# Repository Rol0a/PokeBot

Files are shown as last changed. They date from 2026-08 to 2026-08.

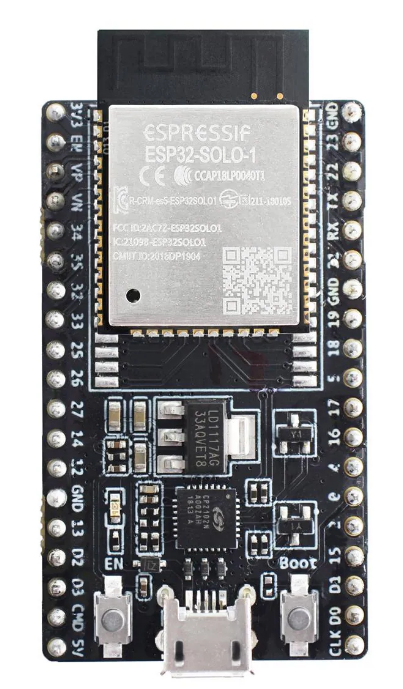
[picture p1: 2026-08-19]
FabricationOutputs/ESP32_FRONT.png

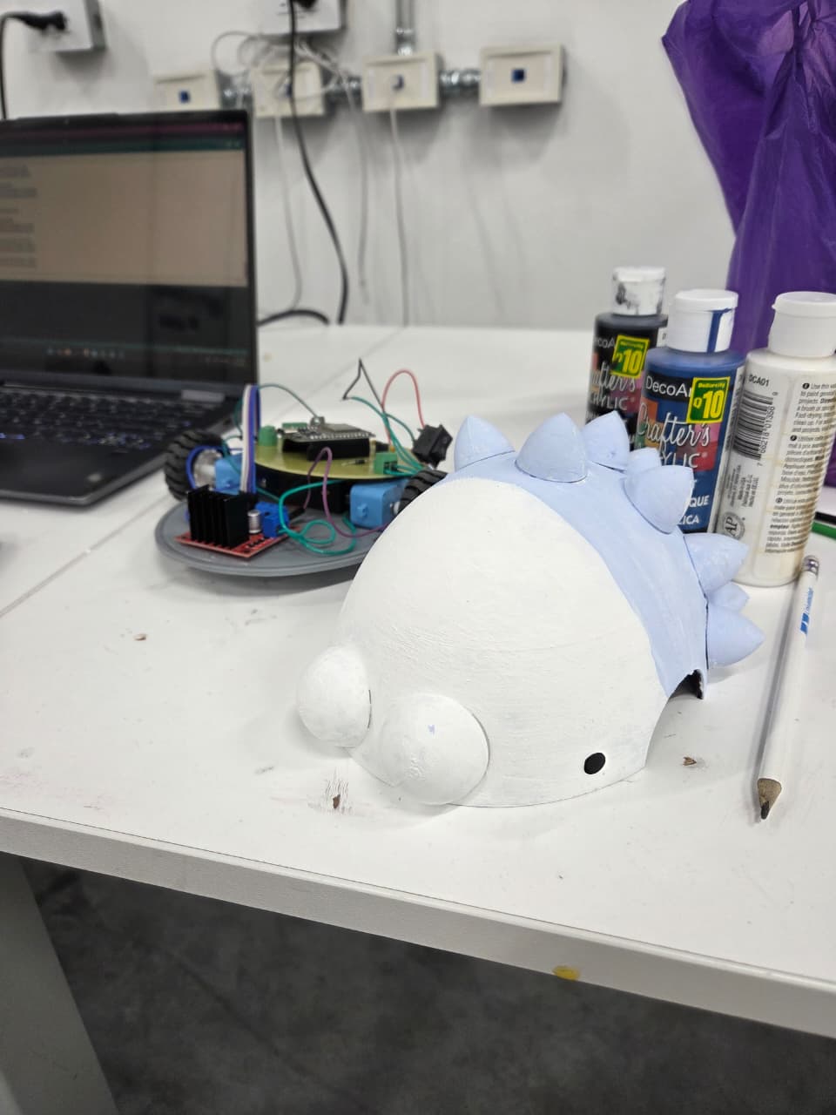
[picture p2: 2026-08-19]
PokeBot_Dismantle.jpeg

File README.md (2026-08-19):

# PokeBot — Bluetooth-Controlled Sumo Robot








> A fully 3D-printed, Bluetooth-controlled sumo robot integrating custom mechanical design, embedded control, power electronics, and PCB fabrication.

---

## Overview

**PokeBot** is a manually controlled sumo robot developed as an integrated electronics, PCB fabrication, embedded systems, and mechanical design project.

The robot was originally inspired by **Snom**, with the objective of translating its general geometry and appearance into a functional sumo robot. The final design uses a **two-wheel differential-drive system**, an **ESP32** for control and Bluetooth communication, and a custom-designed PCB for power conversion and electrical integration.

Every component of the chassis and external enclosure was designed from scratch in **Autodesk Fusion 360** and manufactured using **PLA FDM 3D printing**.

The completed robot participated in three sumo battles, winning **2 out of 3 matches**.

---

## Final Specifications

| Parameter | Final Implementation |
|---|---|
| **Dimensions** | 20 × 20 × 15 cm |
| **Mass** | 420 g |
| **Chassis Material** | PLA |
| **Manufacturing** | FDM 3D Printing |
| **Mechanical CAD** | Autodesk Fusion 360 |
| **Microcontroller** | ESP32 |
| **Drive System** | 2 × DC Gearmotors |
| **Steering** | Differential Drive |
| **Wireless Communication** | Bluetooth |
| **User Interface** | Smartphone |
| **Control Platform** | Dabble GamePad |
| **Battery System** | 2 × 3.7 V Li-ion |
| **Nominal Battery Voltage** | 7.4 V |
| **Charging Module** | TP4056 |
| **Custom PCB** | 7.4 V → 5 V DC Buck Converter |
| **Competition Record** | 2 Wins / 3 Battles |
| **Win Rate** | 66.7% |

---

## System Architecture

```text
                         ┌──────────────────┐
                         │    Smartphone    │
                         │  Dabble GamePad  │
                         └────────┬─────────┘
                                  │
                              Bluetooth
                                  │
                                  ▼
                         ┌──────────────────┐
                         │      ESP32       │
                         │ Control + Comms. │
                         └────────┬─────────┘
                                  │
                             GPIO / PWM
                                  │
                                  ▼
                         ┌──────────────────┐
                         │   Motor Driver   │
                         └────┬────────┬────┘
                              │        │
                              ▼        ▼
                          Motor A    Motor B
                              │        │
                              └───┬────┘
                                  │
                          Differential Drive

                   2 × 3.7 V Li-ion Batteries
                                  │
                                7.4 V
                                  │
                                  ▼
                         ┌──────────────────┐
                         │    Custom PCB    │
                         │  DC Buck Stage   │
                         │   7.4 V → 5 V    │
                         └────────┬─────────┘
                                  │
                                 5 V
                                  │
                                  ▼
                                ESP32
```

---

## Mechanical Design

The complete mechanical structure of PokeBot was designed in **Autodesk Fusion 360**.

This included the:

- Main chassis
- Upper enclosure
- Motor mounting geometry
- Internal component placement
- Battery placement
- Electronics mounting
- External Snom-inspired geometry

The complete structure was manufactured using **PLA** through FDM 3D printing.

### Design Constraints

The mechanical design had to balance several requirements:

- Remain within a **20 × 20 cm footprint**
- Maintain sufficient internal volume for electronics and batteries
- Securely mount both DC motors
- Minimize unnecessary mass
- Survive impacts during competition
- Maintain adequate wheel contact and traction
- Allow access to internal electronics
- Preserve the intended PokeBot appearance

The final assembled robot measured:

**20 cm × 20 cm × 15 cm**

with a total mass of:

**420 g**

---

## Drive System

PokeBot uses two independently controlled DC gearmotors in a **differential-drive configuration**.

No conventional steering mechanism is required. Direction is controlled by independently changing the direction of rotation of each motor.

| Command | Motor A | Motor B | Robot Motion |
|---|---|---|---|
| Forward | Forward | Forward | Forward |
| Reverse | Reverse | Reverse | Reverse |
| Left | Reverse | Forward | Rotate Left |
| Right | Forward | Reverse | Rotate Right |
| Stop | Stop | Stop | Stop |

Driving the motors in opposite directions allows PokeBot to perform approximately **zero-radius turns**, providing high maneuverability during sumo battles.

---

## Electronics

### ESP32 Control

The **ESP32** acts as the central processing and communication unit of the robot.

Its primary responsibilities are:

- Receiving Bluetooth commands
- Processing smartphone GamePad inputs
- Generating motor direction signals
- Generating PWM signals
- Controlling the motor driver
- Coordinating robot movement

Bluetooth communication is handled directly by the ESP32, eliminating the need for a separate wireless communication module.

---

## Bluetooth Control

PokeBot is manually controlled from a smartphone using the **Dabble** platform.

The ESP32 receives commands using the `DabbleESP32` library and maps the GamePad directional inputs directly to robot movements.

```text
UP      → Move Forward
DOWN    → Move Backward
LEFT    → Rotate Left
RIGHT   → Rotate Right
NONE    → Stop
```

This provides a simple wireless human-machine interface without requiring a dedicated physical remote controller.

---

## Motor Control

The ESP32 generates both direction and PWM signals for the two DC motors.

### GPIO Configuration

| Function | ESP32 GPIO |
|---|---:|
| Motor A PWM | GPIO 5 |
| Motor A IN1 | GPIO 18 |
| Motor A IN2 | GPIO 19 |
| Motor B PWM | GPIO 27 |
| Motor B IN1 | GPIO 26 |
| Motor B IN2 | GPIO 25 |
| Motor Driver Standby | GPIO 4 |

### PWM Configuration

```text
PWM Frequency:  1 kHz
Resolution:     8 bits
PWM Range:      0–255
Default Speed:  200
```

The firmware continuously processes Bluetooth input and updates the motor direction and speed accordingly.

The main control structure can be summarized as:

```cpp
Dabble.processInput();

if (GamePad.isUpPressed())
    moveForward(motorSpeed);
else if (GamePad.isDownPressed())
    moveBackward(motorSpeed);
else if (GamePad.isLeftPressed())
    turnLeft(motorSpeed);
else if (GamePad.isRightPressed())
    turnRight(motorSpeed);
else
    stopMotors();
```

> The complete ESP32 firmware is available in the source files of this repository.

---

## Power System

The final PokeBot uses:

**2 × 3.7 V lithium-ion batteries**

providing a nominal combined battery voltage of:

**7.4 V**

The battery system supplies the robot's motor and control electronics while remaining compact enough to fit inside the 3D-printed enclosure.

### Power Architecture

```text
              2 × 3.7 V Li-ion
                      │
                      ▼
                    7.4 V
                      │
             ┌────────┴────────┐
             │                 │
             ▼                 ▼
       Motor System       Custom PCB
                              │
                              ▼
                       Buck Converter
                         7.4 V → 5 V
                              │
                              ▼
                            ESP32
```

A **TP4056** module was incorporated into the battery and charging implementation.

---

## Custom PCB

One of the central electronics components developed for PokeBot was a **custom-designed and fabricated PCB**.

Rather than relying exclusively on external converter modules and loose wiring, the PCB was designed specifically around the electrical requirements of the robot.

### Main Functions

The final PCB performs two primary functions:

1. **DC voltage conversion**
2. **ESP32 electrical interconnection**

The board converts the nominal battery voltage from:

```text
7.4 V DC
   │
   ▼
DC Buck Converter
   │
   ▼
5 V DC
```

The regulated **5 V output** provides the required low-voltage supply for the ESP32-side electronics.

The PCB also provides a dedicated connection interface for the ESP32, improving the organization of the electrical architecture and reducing the amount of loose internal wiring.

---

## Original Electronic Architecture

During the schematic-design stage, PokeBot was divided into several functional subsystems:

```text
              ┌─────────────────┐
              │  Power Supply   │
              └────────┬────────┘
                       │
          ┌────────────┼────────────┐
          │            │            │
          ▼            ▼            ▼
  Microcontroller   Wireless     Motor Driver
       ESP32      Communication    System
          │                         │
          └─────────────────────────┘
                       │
                       ▼
                    Motors
```

The original electrical architecture separated the design into:

- Power supply
- Microcontroller processing
- Bluetooth communication
- Motor driving
- Mechanical actuation

This modular architecture provided the basis for the PCB and system integration stages.

The final physical implementation evolved from the original schematic as component selections and power requirements were refined during prototyping.

---

## Design Evolution

The project went through several iterations between the initial engineering proposal and the final competition robot.

### Initial Concept

The original design established the use of:

- ESP32-based control
- Bluetooth communication
- Two DC gearmotors
- Rechargeable lithium-ion power
- H-bridge motor control
- Custom PCB development
- Fully 3D-printed structure

### Final Implementation

Following fabrication, testing, and system integration, the final architecture consisted of:

- **2 DC motors**
- **2 × 3.7 V lithium-ion batteries**
- **ESP32**
- **Bluetooth smartphone control**
- **Dabble GamePad**
- **TP4056**
- **Custom 7.4 V → 5 V buck-converter PCB**
- **Fully PLA 3D-printed chassis**
- **Fusion 360 mechanical design**

This iterative development process allowed the original design to evolve into a practical competition-ready implementation.

---

## Competition Performance

PokeBot was tested in an actual sumo robot competition rather than exclusively under laboratory conditions.

### Results

```text
┌─────────────────────────────┐
│      COMPETITION RECORD     │
├─────────────────────────────┤
│ Battles              3      │
│ Wins                 2      │
│ Losses               1      │
│ Win Rate          66.7%     │
└─────────────────────────────┘
```

**Final result: 2 wins out of 3 battles.**

The competition provided a complete system-level test involving:

- Wireless communication
- Real-time user control
- Motor response
- Mechanical durability
- Battery performance
- Traction
- Turning capability
- PCB operation
- Electromechanical integration

The final result demonstrated that the complete mechanical, electrical, and embedded system could operate successfully under actual competition conditions.

---

## Repository Structure

A recommended organization for the complete project repository is:

```text
PokeBot/
│
├── README.md
│
├── firmware/
│   └── MotorDriver_Try1.ino
│
├── pcb/
│   ├── schematics/
│   ├── pcb-layout/
│   └── fabrication-files/
│
├── mechanical/
│   ├── fusion360/
│   └── stl/
│
├── documentation/
│   ├── project-proposal.pdf
│   └── schematics.pdf
│
└── media/
    ├── photos/
    └── renders/
```

---

## Technologies Used

### Hardware

- ESP32
- DC Gearmotors
- Motor Driver
- 3.7 V Lithium-ion Batteries
- TP4056
- Custom PCB
- FDM 3D-Printed Components

### Embedded Software

- Arduino IDE
- C/C++
- Dabble
- DabbleESP32
- ESP32 Bluetooth

### Electronic Design

- Schematic Capture
- PCB Design
- DC Power Conversion
- PWM Motor Control
- H-Bridge Motor Control
- PCB Fabrication

### Mechanical Design

- Autodesk Fusion 360
- FDM Additive Manufacturing
- PLA
- Mechanical Assembly

---

## Engineering Skills Demonstrated

PokeBot integrates multiple areas of electrical and mechatronics engineering into a single working system.

### Embedded Systems

- ESP32 programming
- Embedded C/C++
- Bluetooth communication
- Real-time command processing
- GPIO control
- PWM generation

### Electronics

- DC motor control
- H-bridge implementation
- DC power conversion
- Voltage regulation
- Battery integration
- Schematic design
- PCB design
- PCB fabrication
- Electronic assembly and soldering

### Mechanical Engineering

- Mechanical CAD
- Autodesk Fusion 360
- Component packaging
- Motor mounting
- Chassis design
- Design for additive manufacturing
- FDM 3D printing
- PLA prototyping

### Mechatronics

- Electromechanical system integration
- Hardware/software integration
- Differential-drive control
- Power and control integration
- Iterative prototyping
- Physical testing
- Competition-based validation

---

## Project Development Process

The complete project followed an engineering workflow from initial concept to physical validation:

```text
Concept
   │
   ▼
Requirements Definition
   │
   ▼
System Architecture
   │
   ├──────────────┐
   ▼              ▼
Electronic     Mechanical
Design           CAD
   │              │
   ▼              ▼
PCB Design     3D Printing
   │              │
   └──────┬───────┘
          ▼
   Firmware Development
          │
          ▼
   Hardware Assembly
          │
          ▼
   System Integration
          │
          ▼
        Testing
          │
          ▼
      Competition
```

This process required continuous iteration between the mechanical, electrical, and embedded subsystems.

---

## Future Improvements

Several improvements could be implemented in a future revision of PokeBot.

### Electronics

- Integrate the motor driver directly into a revised custom PCB
- Add battery-voltage monitoring
- Add motor-current sensing
- Improve power distribution
- Add low-voltage battery protection
- Reduce the number of external modules
- Improve connector placement and serviceability

### Control

- Add wheel encoders
- Implement closed-loop wheel-speed control
- Add configurable speed profiles
- Implement acceleration limiting
- Improve turning control
- Add autonomous movement modes

### Sensors

- Add infrared reflectance sensors for ring-edge detection
- Add opponent-detection sensors
- Add current sensing for motor-load estimation
- Add telemetry for battery and motor status

### Mechanical Design

- Improve wheel traction
- Optimize center of gravity
- Improve weight distribution
- Reduce chassis mass
- Increase structural rigidity in high-impact areas
- Improve access to batteries and electronics
- Optimize the front geometry for sumo competition

### Autonomous Operation

A future version could transition from manual Bluetooth control to autonomous sumo operation by combining:

```text
Ring Sensors
     │
     ▼
    ESP32 ◄──── Opponent Sensors
     │
     ▼
Decision / Control Algorithm
     │
     ▼
Motor Driver
     │
     ▼
Differential Drive
```

This would allow the robot to detect the arena boundary, locate an opponent, and determine its own movement strategy without direct smartphone input.

---

## Project Outcome

PokeBot successfully progressed through the complete engineering development cycle:

```text
Concept
   ↓
System Architecture
   ↓
Electronic Design
   ↓
PCB Design
   ↓
Mechanical CAD
   ↓
3D Printing
   ↓
Firmware Development
   ↓
Manufacturing
   ↓
System Integration
   ↓
Testing
   ↓
Competition
```

The resulting platform was a:

**420 g**

**20 × 20 × 15 cm**

fully functional sumo robot combining:

- Custom PLA mechanical construction
- Fusion 360 CAD design
- ESP32 embedded control
- Bluetooth communication
- Smartphone-based control
- PWM DC motor control
- Two-motor differential drive
- Lithium-ion battery power
- Custom PCB design and fabrication
- 7.4 V → 5 V DC power conversion

The completed robot successfully won **2 of its 3 competition battles**, providing physical validation of the integrated mechanical, electronic, and embedded design.

---

## Documentation

This repository is intended to preserve the complete development process of PokeBot, including:

- Initial project proposal
- Electronic schematics
- PCB design
- PCB fabrication files
- ESP32 firmware
- Fusion 360 mechanical designs
- STL files
- Final robot photographs
- Competition results

> **Note:** The original proposal and schematic documents represent earlier stages of development. Some component selections and aspects of the power architecture changed during prototyping and integration. The specifications presented in the **Final Specifications** section describe the completed competition version of PokeBot.

---

## Author

**Marcos Rodrigo López Agustín**

Electrical & Mechatronics Engineering  
Universidad del Valle de Guatemala

---

## Disclaimer

This repository documents an academic engineering project developed for educational purposes.

The electrical schematics and initial design documentation represent the project's development process and may contain components or subsystem architectures that differ from the final physical implementation.

When reproducing or modifying the power system, appropriate lithium-ion battery charging, protection, and electrical safety practices should be followed.

---

## Final Result

**PokeBot**

`420 g` • `20 × 20 × 15 cm` • `ESP32` • `Bluetooth` • `Custom PCB` • `Fusion 360` • `PLA` • `2/3 Battles Won`

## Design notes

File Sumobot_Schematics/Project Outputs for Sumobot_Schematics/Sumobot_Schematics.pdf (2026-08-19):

Name | Description | Quantity | Price | Line # | Capacitance | Value | Manufacturer Part Number 1 | Supplier Stock 1 | Supplier 1
GRM033R61A104KE 15D | Chip Multilayer Ceramic Capacitors for General Purpose, 0201, 0.10uF, X5R, 15%, 10%, 10V | 5 | 0.04 | | 100nF | | GRM033R61A104KE15D | 2271006 | Mouser
ZRB18AR61E106KE 01L | Low Acoustic Noise Chip Multilayer Ceramic Capacitors on Interposer Board for General Purpose ZRB Series 0603 Package 1.2mm X5R @ 15% 25Vdc 10uF @ 10% | 3 | 1.32 | | | 10uF 25V | ZRB18AR61E106KE01L | 8125 | Mouser
ECQ-E2105KF | ECQ-E2105KF Cap Film 1uF 250V PET 10% (18.5 X 7.4 X 15mm) Radial 15mm 105 C Bulk | 1 | 0.1853 | | 1µF | | ECQ-E2105KF | 787 | Arrow Electronics
CAP 330nF 50V 1210(3225) | CAP 330nF 50V ±10% 1210 (3225 Metric) Thickness 1.05mm SMD | 1 | 0.0187 | | | 330nF | C1210C334K5RAC | 75 | Arrow Electronics
1N5819HW-7-F | DIODE SCHOTTKY 40V 1A SOD123 | 1 | 0.29 | | 110pF | | 1N5819HW-7-F | 19348 | DigiKey
HSMC-C280 | LED RED DIFFUSED 0402 SMD | 1 | 0.49 | | | | HSMC-C280 | 51699 | Mouser
AI-1223-TWT-3V-2-R | BUZZER MAGNETIC 3V 12MM TH | 1 | 1.49 | | | | AI-1223-TWT-3V-2-R | 20662 | Mouser
ESP32-WROOM-32E (16MB) | RX TXRX MOD WIFI TRACE ANT SMD | 1 | | | | | ESP32-WROOM-32E (16MB)
2N3904 | General Purpose Transistor, NPN Silicon, 200 mA, 60 V, -55 to 150 degC, 3-Pin TO-92, RoHS, Bulk | 1 | | | | | 2N3904
MCT0603HC1002FP 500 | RES SMD 100 OHM 1% 1/8W 0603 | 1 | 0.46 | | | | MCT0603HC1002FP500 | 741 | Mouser
CRCW020127K0JNE D | | 1 | 0.1 | | | | CRCW020127K0JNED | 11257 | Mouser
RN73R1ETTP5101F 25 | 5.1kΩ ±1% 0.063W, 1/16W Chip Resistor 0402 (1005 Metric) Moisture Resistant Thin Film | 1 | | | | 5.1k | RN73R1ETTP5101F25
L298N | Dual Full-Bridge Driver, 4.8 to 46 V, -40 to 150 degC, 15-Pin FM (MW 15L), RoHS, Tube | 1 | 11.53 | | | | L298N | 1886 | Mouser
AMS1117-3.3 | LDO Voltage Regulators 1A, 3.3V | 1 | | | | | AMS1117-3.3
UA78M08CKCS | Fixed Regulator with 10.5 to 25 V Input and 8 V Output, 0 to 125 degC, 3-Pin TO-220 (KCS), Pb-Free (RoHS) | 1 | 1.5 | | | | UA78M08CKCS | 916 | Mouser

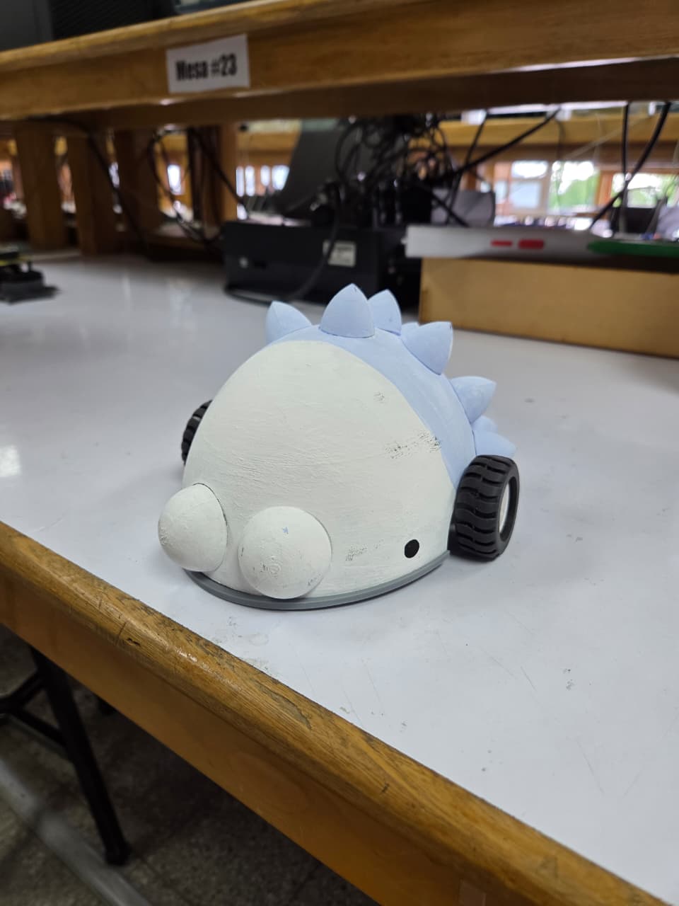
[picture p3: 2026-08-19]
PokeBot.jpeg

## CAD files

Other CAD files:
CAD Files/BOQUILLA.f3d
CAD Files/Base_Sumo.f3d
CAD Files/Cover_Sumo.f3d
CAD Files/MOTOR_JOINT.f3d
CAD Files/PICOS.f3d

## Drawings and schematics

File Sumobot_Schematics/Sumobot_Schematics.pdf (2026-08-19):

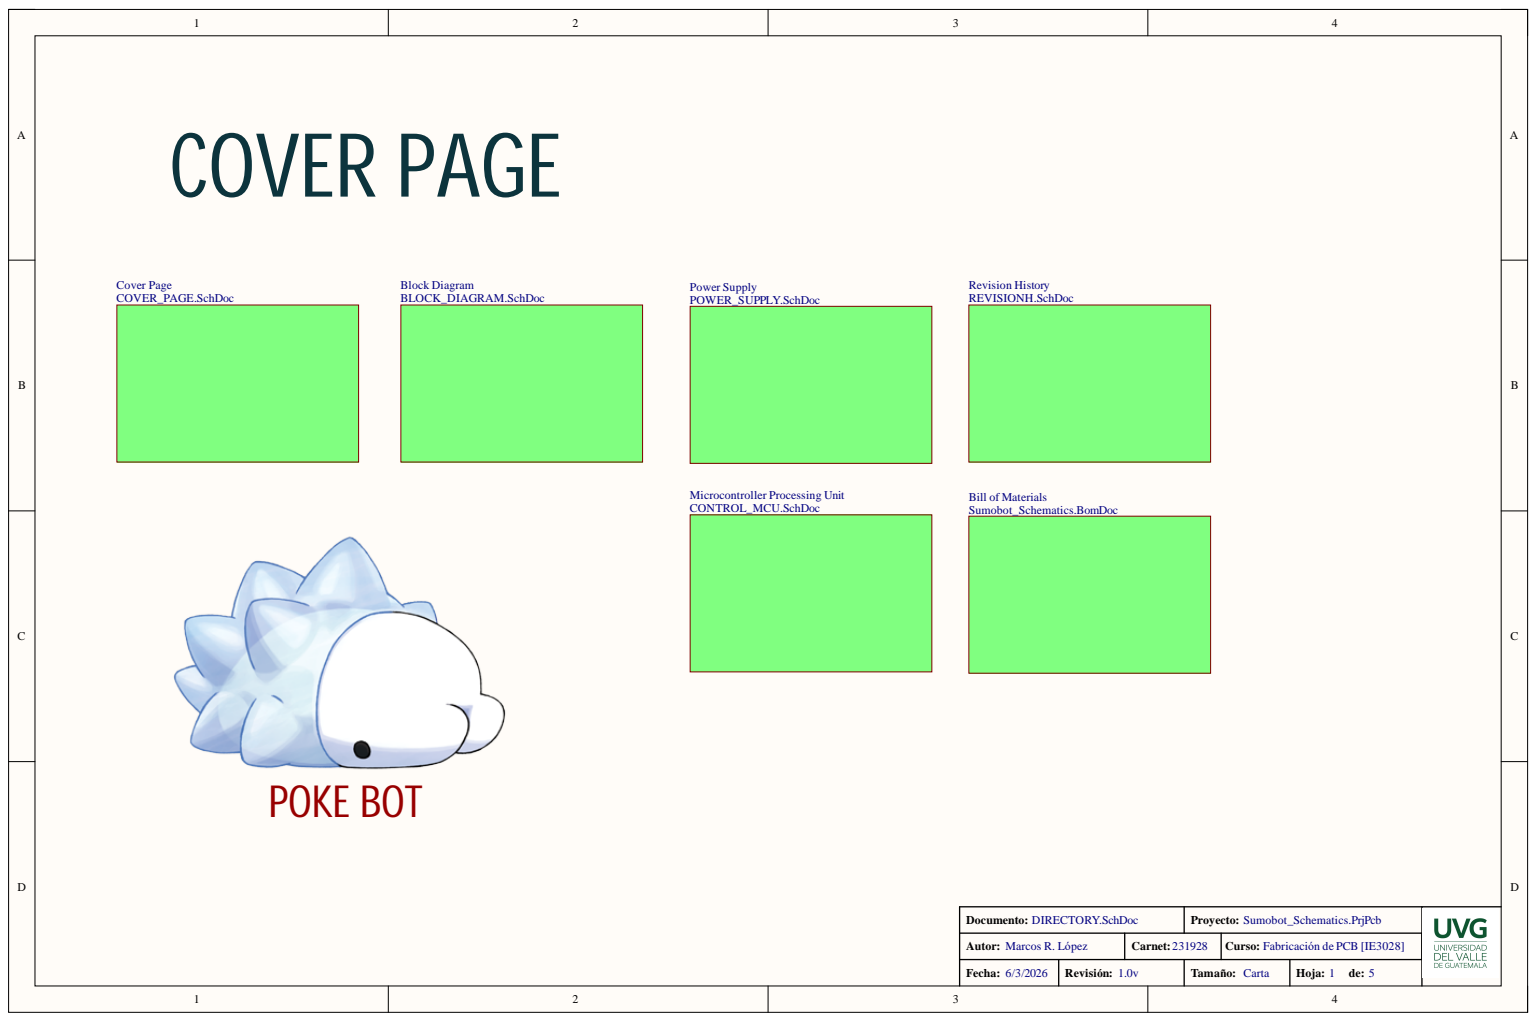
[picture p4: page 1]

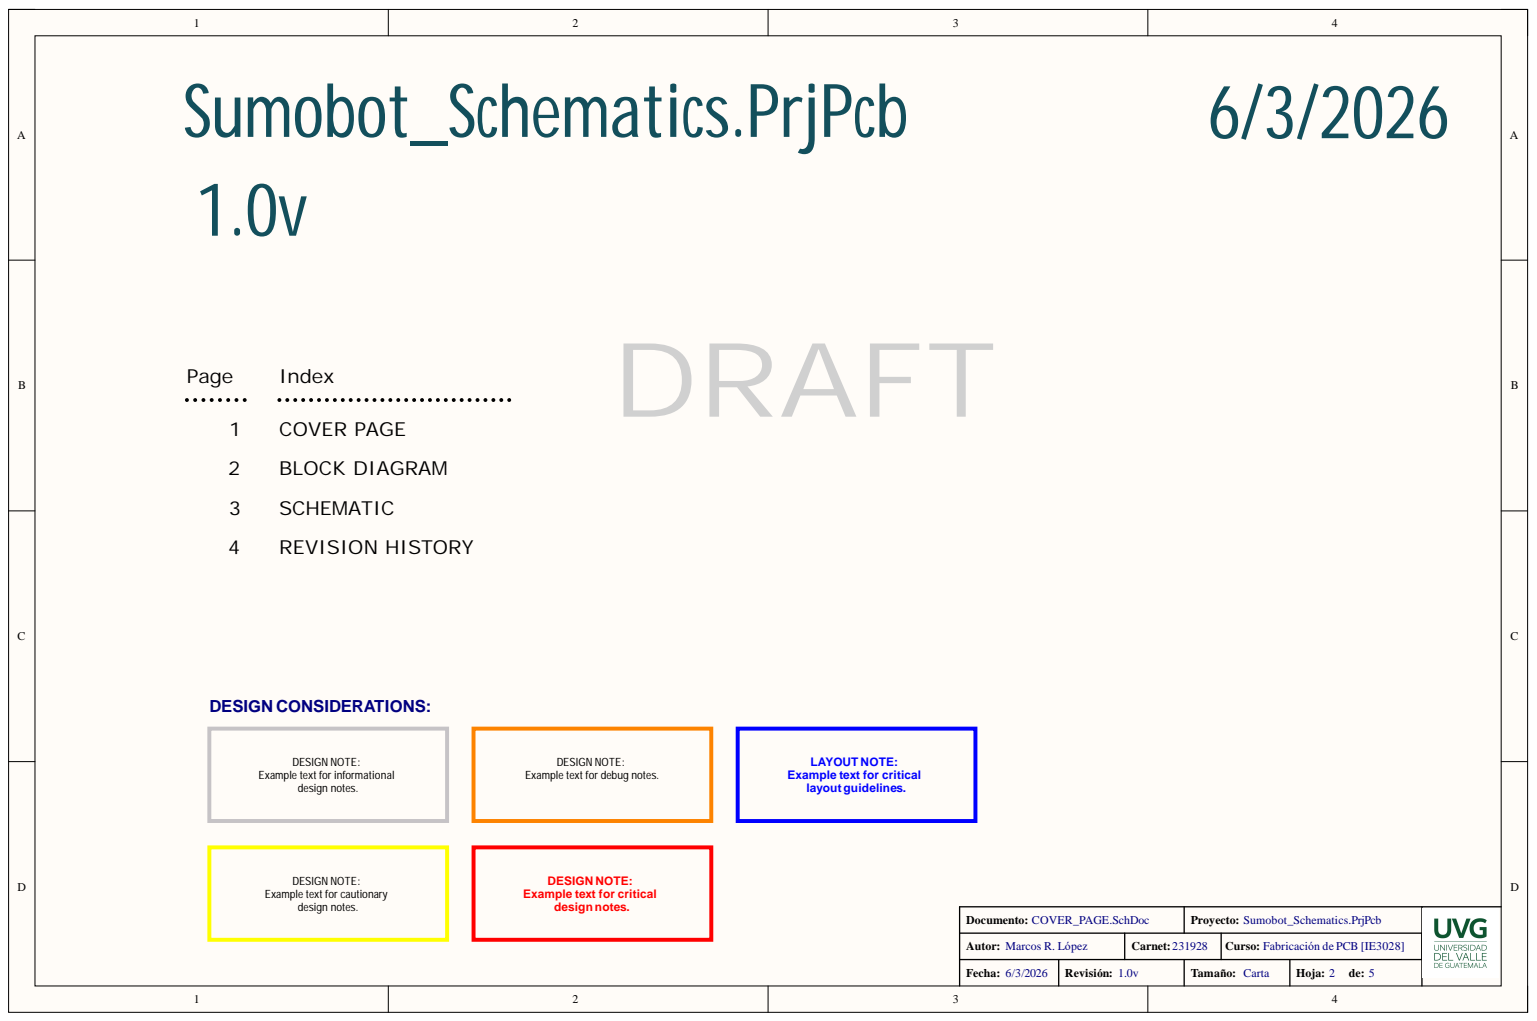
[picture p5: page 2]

DESIGN NOTE:
Example text for debug notes.

LAYOUT NOTE:
Example text for critical
layout guidelines.

Example text for informational

Example text for cautionary
design notes.

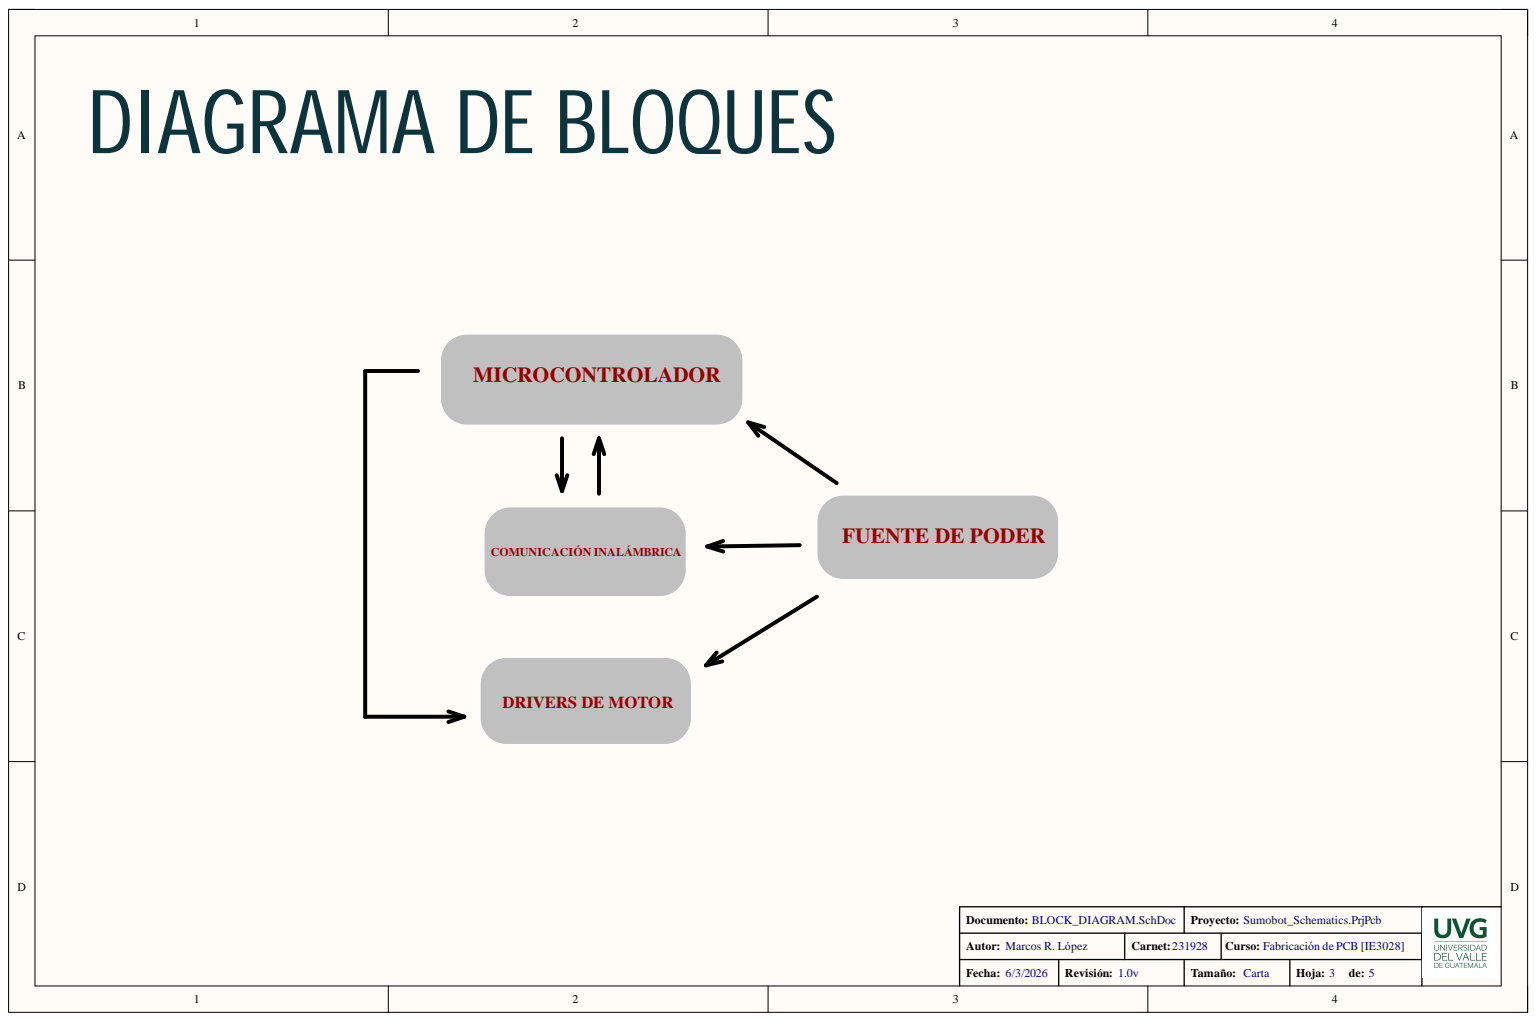
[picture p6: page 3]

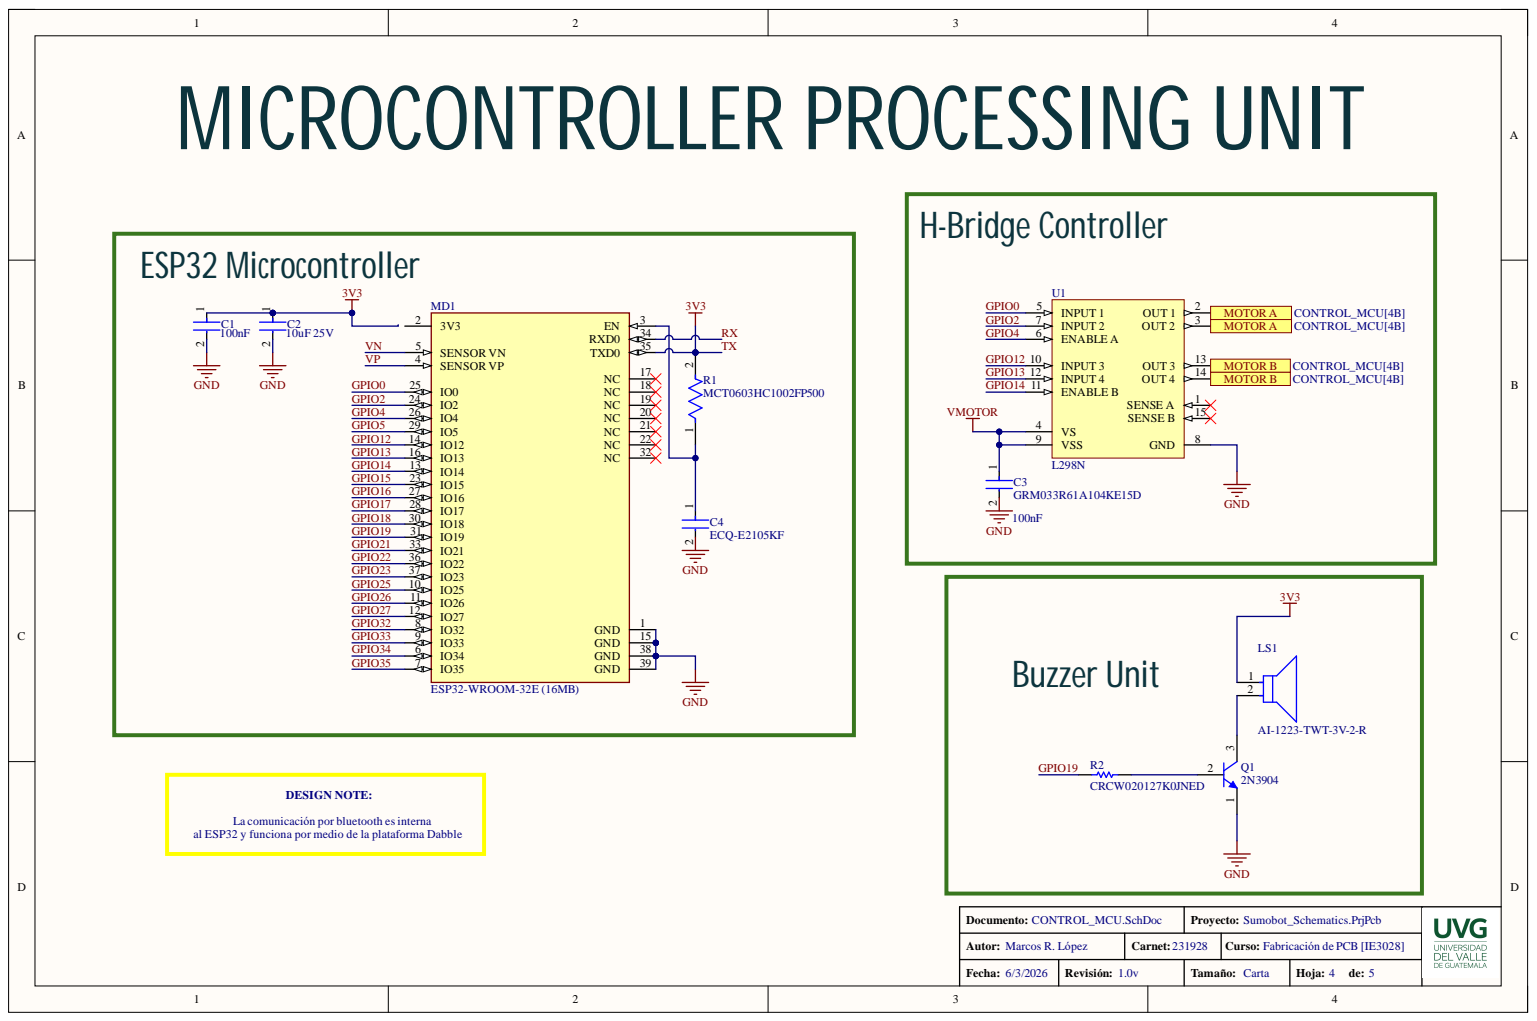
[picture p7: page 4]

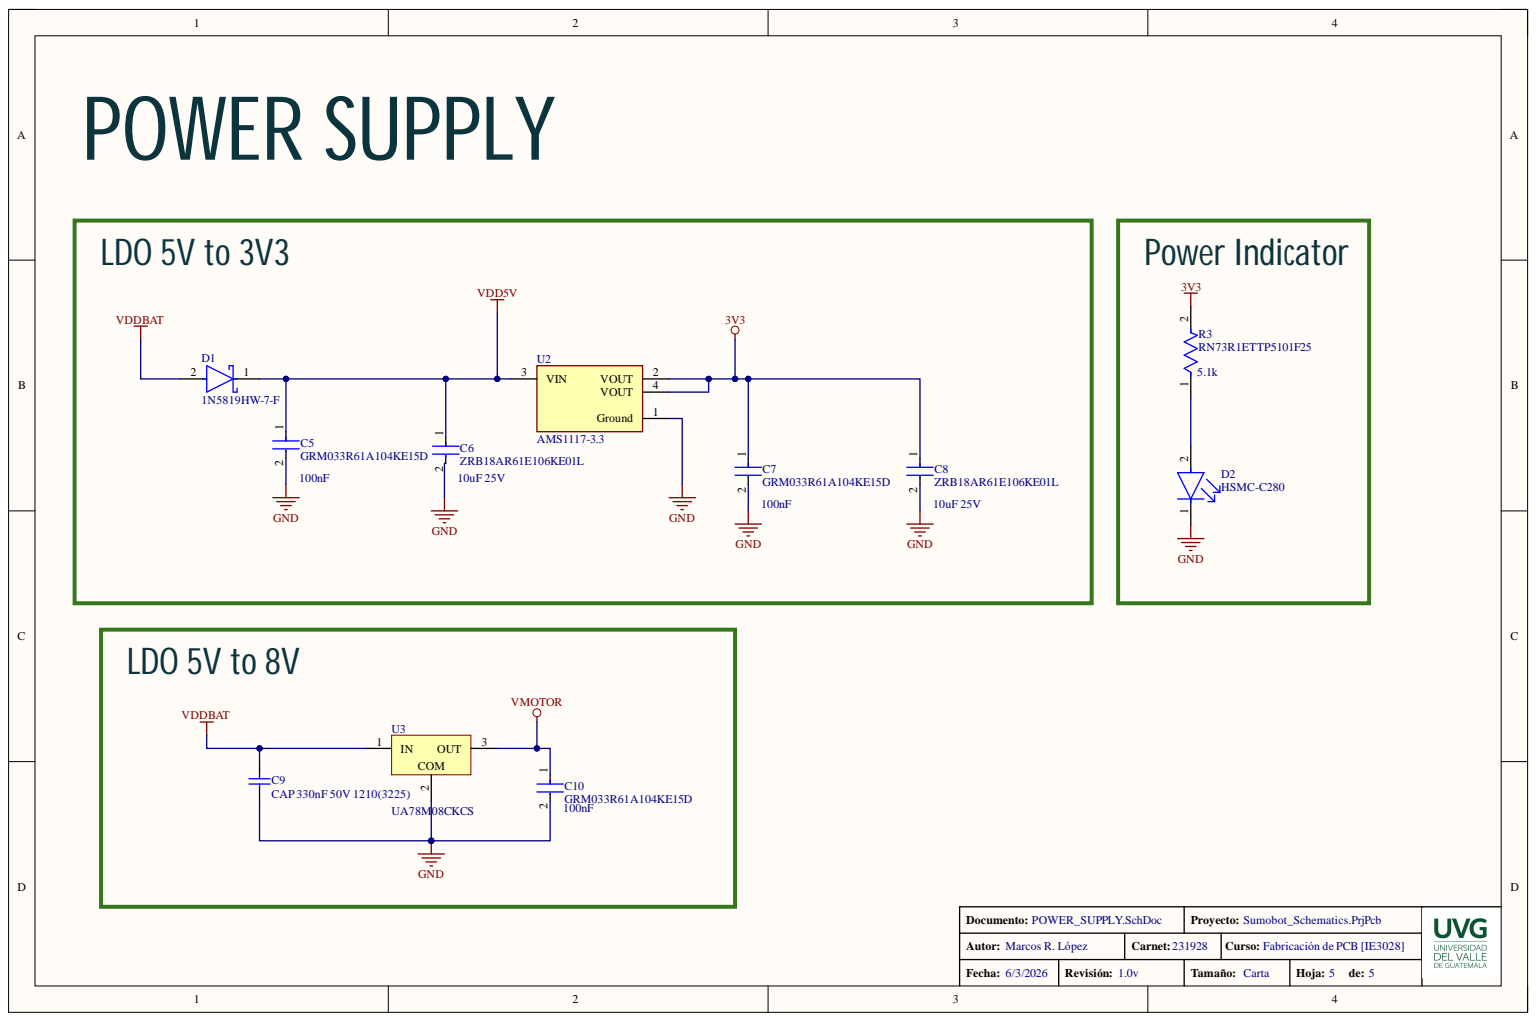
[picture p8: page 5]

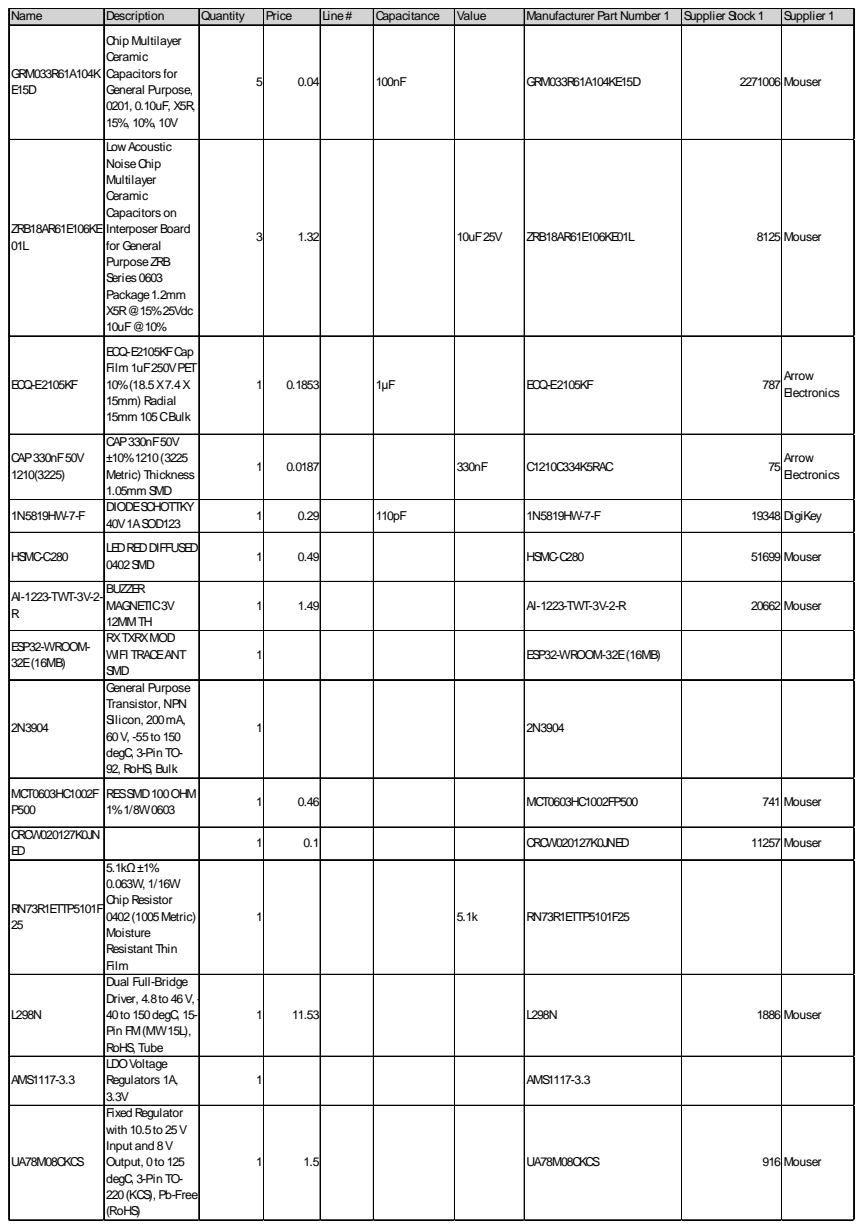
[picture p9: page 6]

Name | Description | Quantity | Price | Line# | Capacitance | Value | Manufacturer Part Number 1 | Supplier Stock 1 | Supplier 1

GRM033R61A104K E15D | Chip Multilayer Ceramic Capacitors for General Purpose, 0201, 0.10uF, X5R, 15%, 10%, 10V | 5 | 0.04 | | 100nF | | GRM033R61A104KE15D | 2271006 Mouser

ZRB18AR61E106KE 01L | Low Acoustic NoiseChip Multilayer Ceramic Capacitors on Interposer Board for General PurposeZRB Series 0603 Package1.2mm X5R@15%25Vdc 10uF@10% | 3 | 1.32 | | | 10uF25V | ZRB18AR61E106KE01L | 8125 Mouser

ECQ-E2105KF | ECQ-E2105KFCap Film 1uF250VPET 10%(18.5X7.4X 15mm) Radial 15mm 105CBulk | 1 | 0.1853 | | 1µF | | ECQ-E2105KF | 787 Arrow | Electronics

CAP330nF50V 1210(3225) | CAP330nF50V ±10%1210(3225 Metric) Thickness 1.05mm SMD | 1 | 0.0187 | | | 330nF | C1210C334K5RAC | 75 Arrow | Electronics

1N5819HW-7-F | DIODESCHOTTKY 40V1ASOD123 | 1 | 0.29 | | 110pF | | 1N5819HW-7-F | 19348 DigiKey

HSMC-C280 | LEDREDDIFFUSED 0402SMD | 1 | 0.49 | | | | HSMC-C280 | 51699 Mouser

AI-1223-TWT-3V-2-R | BUZZER MAGNETIC3V 12MMTH | 1 | 1.49 | | | | AI-1223-TWT-3V-2-R | 20662 Mouser

ESP32-WROOM-32E(16MB) | RXTXRXMOD WIFI TRACEANT SMD | 1 | | | | | ESP32-WROOM-32E(16MB)

2N3904 | General Purpose Transistor, NPN Silicon, 200mA, 60V, -55to 150 degC, 3-Pin TO-92, RoHS, Bulk | 1 | | | | | 2N3904

MCT0603HC1002F P500 | RESSMD100OHM 1%1/8W0603 | 1 | 0.46 | | | | MCT0603HC1002FP500 | 741 Mouser

CRCW020127K0JN ED | | 1 | 0.1 | | | | CRCW020127K0JNED | 11257 Mouser

RN73R1ETTP5101F 25 | 5.1kΩ±1% 0.063W, 1/16W Chip Resistor 0402(1005Metric) Moisture Resistant Thin Film | 1 | | | | 5.1k | RN73R1ETTP5101F25

L298N | Dual Full-Bridge Driver, 4.8to 46V, -40to 150degC, 15-Pin FM(MW15L), RoHS, Tube | 1 | 11.53 | | | | L298N | 1886 Mouser

AMS1117-3.3 | LDOVoltage Regulators 1A, 3.3V | 1 | | | | | AMS1117-3.3

UA78M08CKCS | Fixed Regulator with 10.5to 25V Input and 8V Output, 0to 125 degC, 3-Pin TO-220(KCS), Pb-Free (RoHS) | 1 | 1.5 | | | | UA78M08CKCS | 916 Mouser

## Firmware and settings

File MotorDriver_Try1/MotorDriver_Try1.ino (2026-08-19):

#define CUSTOM_SETTINGS
#define INCLUDE_GAMEPAD_MODULE
#include <DabbleESP32.h>

// ---------------- Pin Definitions ----------------
// Motor A
#define PWMA 5      // D5 -> GPIO5
#define AIN1 18     // D18 -> GPIO18
#define AIN2 19     // D19 -> GPIO19

// Motor B
#define PWMB 27     // D27 -> GPIO27
#define BIN1 26     // D26 -> GPIO26
#define BIN2 25     // D25 -> GPIO25

// Standby (moved from GPIO34 to GPIO4)
#define STBY 4      // D4 -> GPIO4

// ---------------- PWM Configuration (Core 2.x) ----------------
#define CHANNEL_A 0
#define CHANNEL_B 1
#define PWM_FREQ 1000
#define PWM_RESOLUTION 8   // 0–255

int motorSpeed = 200;

// ---------------- Setup ----------------
void setup()
{
  Serial.begin(115200);
  Dabble.begin("ESP32_Car");

  pinMode(AIN1, OUTPUT);
  pinMode(AIN2, OUTPUT);
  pinMode(BIN1, OUTPUT);
  pinMode(BIN2, OUTPUT);
  pinMode(STBY, OUTPUT);

  // Enable motor driver
  digitalWrite(STBY, HIGH);

  // LEDC setup (ESP32 Core 2.x)
  ledcSetup(CHANNEL_A, PWM_FREQ, PWM_RESOLUTION);
  ledcAttachPin(PWMA, CHANNEL_A);

  ledcSetup(CHANNEL_B, PWM_FREQ, PWM_RESOLUTION);
  ledcAttachPin(PWMB, CHANNEL_B);
}

// ---------------- Main Loop ----------------
void loop()
{
  Dabble.processInput();

  if (GamePad.isUpPressed())
  {
    moveForward(motorSpeed);
  }
  else if (GamePad.isDownPressed())
  {
    moveBackward(motorSpeed);
  }
  else if (GamePad.isLeftPressed())
  {
    turnLeft(motorSpeed);
  }
  else if (GamePad.isRightPressed())
  {
    turnRight(motorSpeed);
  }
  else
  {
    stopMotors();
  }
}

// ---------------- Movement Functions ----------------
void moveForward(int speed)
{
  digitalWrite(AIN1, HIGH);
  digitalWrite(AIN2, LOW);
  digitalWrite(BIN1, HIGH);
  digitalWrite(BIN2, LOW);

  ledcWrite(CHANNEL_A, speed);
  ledcWrite(CHANNEL_B, speed);
}

void moveBackward(int speed)
{
  digitalWrite(AIN1, LOW);
  digitalWrite(AIN2, HIGH);
  digitalWrite(BIN1, LOW);
  digitalWrite(BIN2, HIGH);

  ledcWrite(CHANNEL_A, speed);
  ledcWrite(CHANNEL_B, speed);
}

void turnLeft(int speed)
{
  digitalWrite(AIN1, LOW);
  digitalWrite(AIN2, HIGH);
  digitalWrite(BIN1, HIGH);
  digitalWrite(BIN2, LOW);

  ledcWrite(CHANNEL_A, speed);
  ledcWrite(CHANNEL_B, speed);
}

void turnRight(int speed)
{
  digitalWrite(AIN1, HIGH);
  digitalWrite(AIN2, LOW);
  digitalWrite(BIN1, LOW);
  digitalWrite(BIN2, HIGH);

  ledcWrite(CHANNEL_A, speed);
  ledcWrite(CHANNEL_B, speed);
}

void stopMotors()
{
  ledcWrite(CHANNEL_A, 0);
  ledcWrite(CHANNEL_B, 0);

  digitalWrite(AIN1, LOW);
  digitalWrite(AIN2, LOW);
  digitalWrite(BIN1, LOW);
  digitalWrite(BIN2, LOW);
}

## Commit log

2026-08-19 Esquemáticos de Funcionamiento
    [BLOCK_DIAGRAM.SchDoc, CONTROL_MCU.SchDoc, COVER_PAGE.SchDoc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]
2026-08-19 Fabrication Files and PCB Design
    [ESP32_DevKitCWROOM32.PcbLib, ESP32_DevKitCWROOM32.SchLib, FabricationSumo.SchDoc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]
2026-08-19 CAD Files
    [BOQUILLA.f3d, Base_Sumo.f3d, Cover_Sumo.f3d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]
